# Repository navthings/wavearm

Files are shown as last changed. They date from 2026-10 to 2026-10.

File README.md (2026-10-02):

# wavearm

a little desk robot arm that copies whatever my arm is doing. i wave, it waves back.

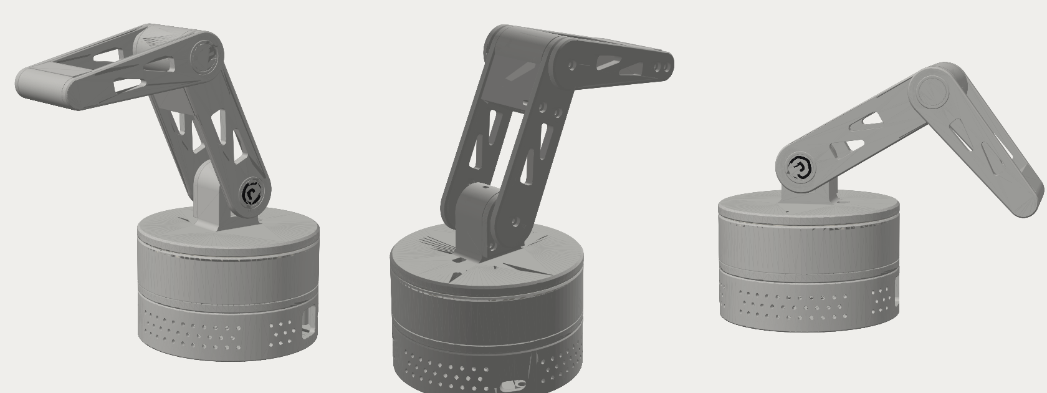
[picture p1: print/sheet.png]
renders


it started as a two joint thing that could only wave. then i found an old raspberry pi 5 in a drawer and it turned into a proper three joint arm: the base spins, and the shoulder and elbow tilt. the pi hides in the base and moves the servos, and my macbook webcam does the watching. it finds my shoulder, elbow and wrist, works out the angles, and sends them to the pi over wifi.

the whole thing is about $40 of parts plus a lot of light grey PLA.

## how it works

```
mac webcam -> mediapipe finds my arm -> shoulder + elbow angles -> wifi -> pi 5 -> three servos
```

the design is all code (`arm3.py`, using cadquery), so every size is a number at the top of the file. change one, run `python3 arm3.py && python3 plates.py` and you get new print files packed onto a1 mini plates. `check3.py` swings both joints through their whole range and makes sure nothing crashes into anything.

it can also do head tracking (`software/track.py`), where the base just turns to look at you. more on the software in [software/README.md](software/README.md).

## what you need

| part | where | price |
|---|---|---|
| 1x MG90S metal gear servo (shoulder, it holds the whole arm up) | [altronics Z6444](https://www.altronics.com.au/product/z6444-mg90s-metal-geared-micro-servo) | $13.95 |
| 2x 9g plastic servo (base and elbow, barely any load) | altronics Z6392 | $9.95 each |
| jumper wires, pin to socket | altronics P1021 | $4.00 |
| M3x10 screws, 25 pack (it uses 12) | altronics H3120A | $2.60 |
| raspberry pi 5 + the official 27W power supply | had one | |
| a usb stick (8gb+) to boot the pi from | had one | |

no soldering, and no tiny M2.5 screws because the pi just sits on printed pegs. the pi boots off a usb stick that plugs into the blue usb port through a window on the right side of the base, so no sd card needed.

## printing

i print on a bambu a1 mini, so everything is laid out on plates in `print/a1mini/`. 0.2mm layers, 3 walls, 15% gyroid, no supports on anything.

everything is packed onto 4 plates, as many parts per plate as fit:

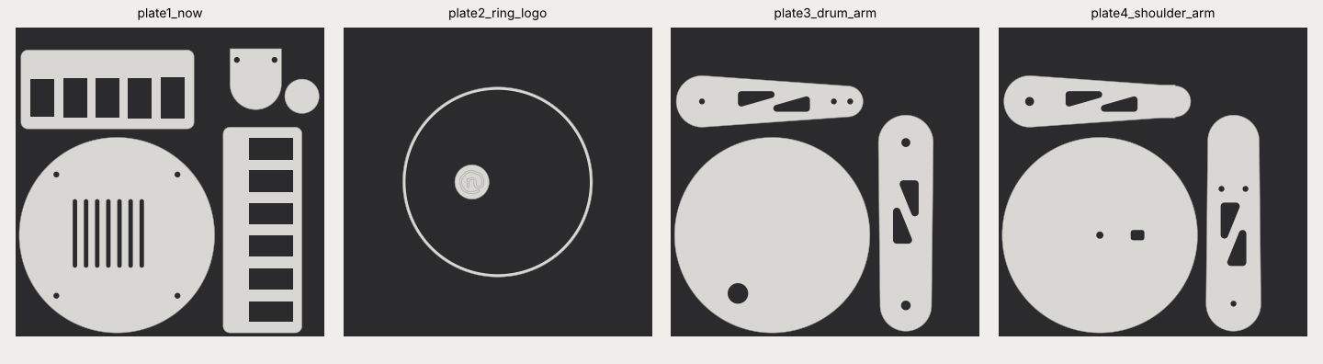
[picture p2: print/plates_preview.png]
plates


| plate | whats on it | when |
|---|---|---|
| plate1_now | tray (25% infill so the base is heavy), both servo gauge strips, servo cover, elbow cap | first. nothing on it depends on servo sizes and theres no pause, so you can leave it running |
| plate2_ring_logo | light ring + logo cap | when youre home, it pauses at 1.6mm to swap colour for the logo |
| plate3_drum_arm | drum, upper arm front, forearm back | after the gauge test |
| plate4_shoulder_arm | shoulder + platter, upper arm back, forearm front | after the gauge test. brim on, the forearm has a tall thin bit |

the gauge strips are rows of slots in slightly different sizes. push each servo into them and the tightest slot it fits is its real size, so you dont need calipers. put those numbers into `arm3.py`, run `python3 arm3.py && python3 plates.py`, then print plates 3 and 4.

the loose STLs and STEP files (for fusion / onshape) are in `print/` too.

## wiring

| servo | signal | 5V | GND |
|---|---|---|---|
| base | pin 32 (GPIO 12) | pin 2 | pin 6 |
| shoulder | pin 33 (GPIO 13) | pin 4 | pin 14 |
| elbow | pin 12 (GPIO 18) | shares pin 2 or 4 | pin 9 |

the pi only has two 5V pins, so the elbow shares one. strip two jumper wires, twist them together, tape it.

## putting it together

1. centre all three servos at 90 degrees before any horns go on, otherwise it waves lopsided
2. pi onto the pegs in the tray, usb-c lined up with the hole at the back and the blue usb ports lined up with the window on the side. plug the boot stick in from outside
3. base servo into the drum, drum onto the tray (4 screws from underneath)
4. ring into the drum, horn into the bottom of the platter, platter onto the servo, screw it down through the little hole in the top of the tower
5. shoulder servo slides into the tower from the back, cover clamps it in
6. elbow servo goes inside the top of the upper arm, then the back plate screws on
7. forearm onto the elbow, back plate on, pivot screws snug but not tight
8. press the caps in

## older stuff

`v1/` has the first version, the two joint waving arm. kept it because the three joint one grew out of it.

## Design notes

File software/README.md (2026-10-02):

# software

your mac webcam watches you, works out where the robot should point, and sends that to the pi over wifi. the pi just moves the servos.

- `armtrack.py` (mac): copies your arm. your shoulder and elbow angles go straight to the robots shoulder and elbow
- `track.py` (mac): head tracking, the base turns to face you
- `arm.py` (pi): receives angles and drives the three servos

## on the mac (arm copy)

```zsh
cd ~/Documents/Projects/wavearm/software
source .venv312/bin/activate
python armtrack.py --pi raspberrypi.local
```

`.venv312` is python 3.12 with mediapipe 0.10.14 (the classic cpu pose model, the newer one crashes on macs trying to use metal). it runs about 15ms a frame.

keys: a = switch which arm it copies, s / e = flip shoulder / elbow direction if it moves the wrong way, left/right = turn the base, w = save, q = quit. stand back far enough that your shoulder, elbow and wrist are all in frame.

## on the pi

add this to `/boot/firmware/config.txt` and reboot (hardware pwm on GPIO 12 and 13, arm.py switches GPIO 18 on itself):

```
dtoverlay=pwm-2chan,pin=12,func=4,pin2=13,func2=4
```

```zsh
scp arm.py pi@raspberrypi.local:~
ssh pi@raspberrypi.local "sudo python3 arm.py"
```

## wiring (no soldering)

| servo | signal | 5V | GND |
|---|---|---|---|
| base (plastic) | pin 32 (GPIO 12) | pin 2 | pin 6 |
| shoulder (metal MG90S) | pin 33 (GPIO 13) | pin 4 | pin 14 |
| elbow (plastic) | pin 12 (GPIO 18) | shares pin 2 or 4 | pin 9 |

the pi only has two 5V pins, so the elbow shares one: strip 1cm off two jumper wires, twist them together, tape it. use the official 27W pi power supply or the pi will reboot when the servos start.

## testing without the pi

`python3 arm.py --dry` in one window, `python armtrack.py --pi 127.0.0.1` in another. arm.py prints the angles instead of moving anything.

## tuning (top of arm.py)

- `PULSE_MIN` / `PULSE_MAX`: if a joint doesnt reach its full swing or buzzes at the ends
- `CENTRE`: if straight up isnt quite straight, change 90 to 85 or 95 for that joint
- `MAX_SPEED`: lower = calmer, higher = snappier

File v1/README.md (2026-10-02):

# wave arm

two joint desk arm. the drum turns to face you, the link swings side to side to wave. a raspberry pi 5 lives in the base, so it runs on its own (camera, face tracking, sprout) with no laptop.

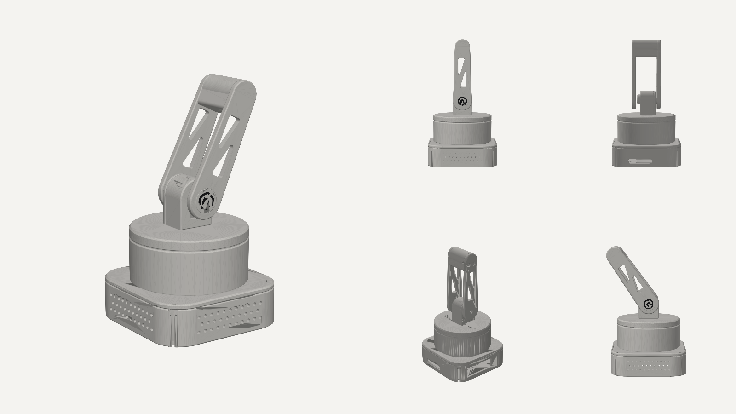
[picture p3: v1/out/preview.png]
preview


## files

- `wavearm.py` the actual design. every size is a variable at the top, change one and rerun `python3 wavearm.py`
- `out/*.step` open these in fusion 360, onshape or autocad (IMPORT) to look around and edit
- `out/wave_arm_assembly.step` everything put together, with dummy servos and the pi in place
- `out/*.stl` already in print orientation, drag straight into bambu studio
- `check.py` checks nothing collides across the whole swing (including the pi in the tray)
- `software/` head tracking: mac webcam finds you, pi moves the arm (see software/README.md)
- `wavearm_esp32.py` the older version with a tiny esp32 board in the drum instead of a pi

## parts list (about A$55 at altronics)

- raspberry pi 5 (already have) + its active cooler + the official 27W usb-c power supply. a weaker charger will make it reboot when the servos move
- 3x MG90S micro servo (2 + 1 spare). altronics Z6444
- male to female jumper wires (servo plug to pi pins)
- M3 button head screws: 4x M3x8 (tray to drum), 2x M3x10 (cover), 1x M3x8 (rear pivot), 2x M3x12 (link)
- 4x M2.5x6 screws for the pi
- 4x 10mm rubber feet
- optional: 470uF capacitor + mini breadboard if the pi reboots when servos start

## printing

- PLA, matte light grey looks closest to the reference. 0.2mm layers, 3 walls, 15% gyroid. tray at 25% so it's heavier
- the tray and the drum are separate prints (tray open side up, drum on its flat lid)
- no supports on anything, every part already sits on its flat face
- hub cap: print `cap.stl` + `cap_logo.stl` together as two colours (AMS), or print `cap_onepiece.stl` and add a filament change at 1.6mm
- print `cap.stl` first and check it presses into the link. if it's loose or tight, change the 0.15 next to `CAP_D` in the code

## build order

1. measure your servos with calipers and fix the `S_` numbers at the top of `wavearm.py` before printing anything big
2. centre both servos at 90 degrees before any horn goes on (one line of code). if you skip this the arm waves lopsided
3. pi into the tray: usb + ethernet at the back opening, 4x M2.5 into the standoffs. servo 1 drops into the cradle in the drum, shaft up, two tab screws. its cable goes out the side slot and down the hole in the drum floor. drum onto the tray, 4x M3x8 up from underneath
4. screw servo 1's horn into the pocket under the platter, push the platter onto the spline, then put the horn screw in from above through the little hole in the top of the tower
5. thread servo 2's cable down the slot in the tower floor, slide the servo in from the back, shaft forward. the cover clamps it, 2x M3x10
6. horn into the pocket on the back of the front link, push onto servo 2's spline, horn screw in. back plate on with 2x M3x12 into the bridge, M3x8 into the rear boss (snug, not tight, it's a pivot)
7. press the hub cap in

## wiring (no soldering)

| servo wire | base servo | shoulder servo |
|---|---|---|
| red (5V) | pin 2 | pin 4 |
| brown (GND) | pin 6 | pin 14 |
| orange (signal) | pin 32 (GPIO 12) | pin 33 (GPIO 13) |

- GPIO 12 and 13 are hardware PWM on the pi 5, so the servos dont jitter. normal software PWM makes them twitch
- the pi gets power through the side slot (usb-c, the plug reaches in about 13mm). hdmi is in the same slot if you ever need a screen

## numbers

- shoulder pivot 103mm up, arm tip 203mm up, footprint 112mm square
- link swings ±90 degrees without hitting anything (`python3 check.py`)

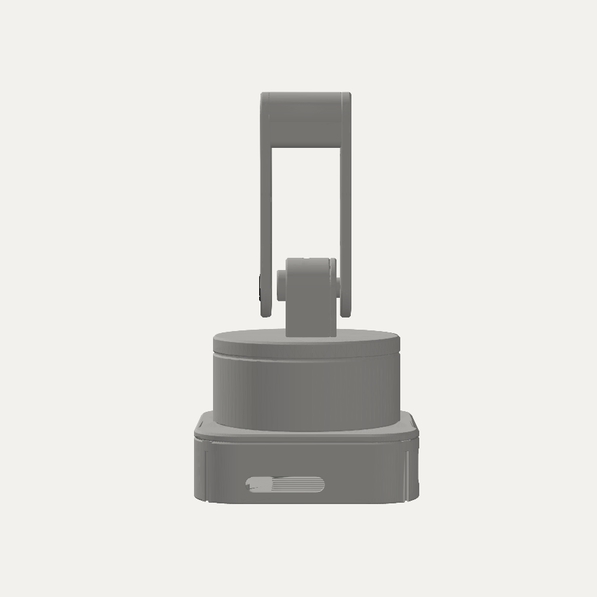
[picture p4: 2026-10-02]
v1/out/render_side.png

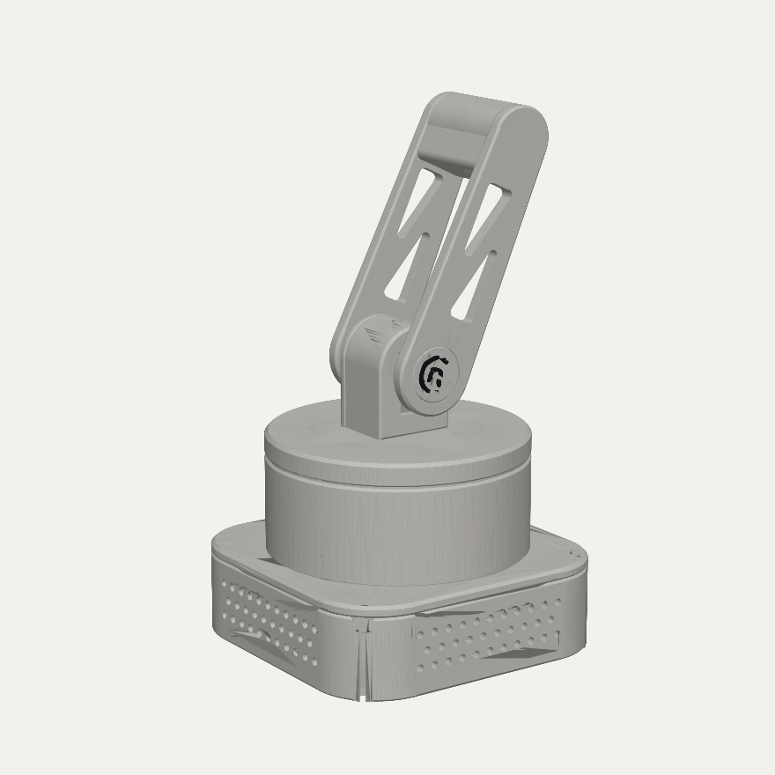
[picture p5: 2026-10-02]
v1/out/render_hero.png

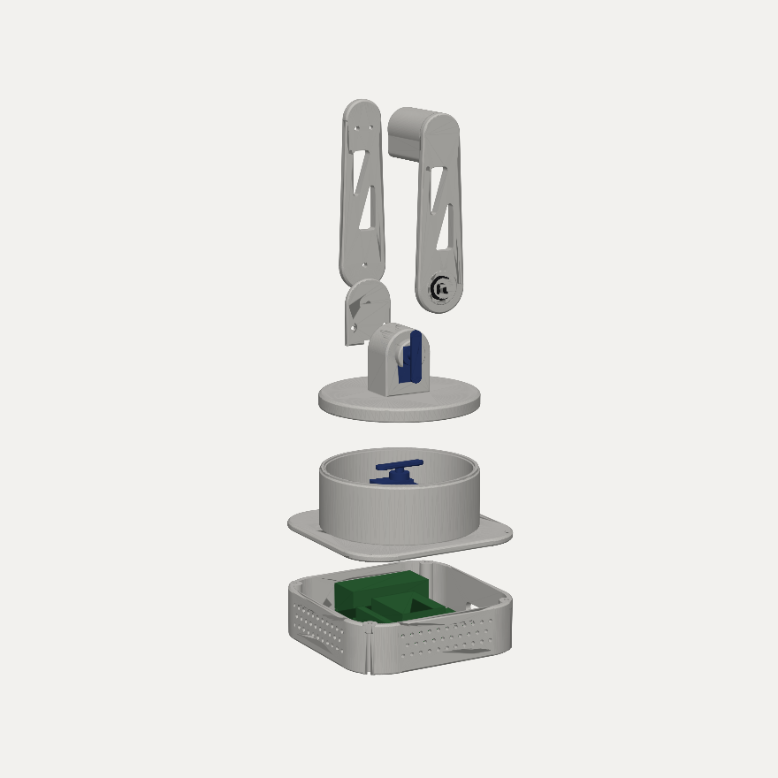
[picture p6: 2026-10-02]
v1/out/render_exploded.png

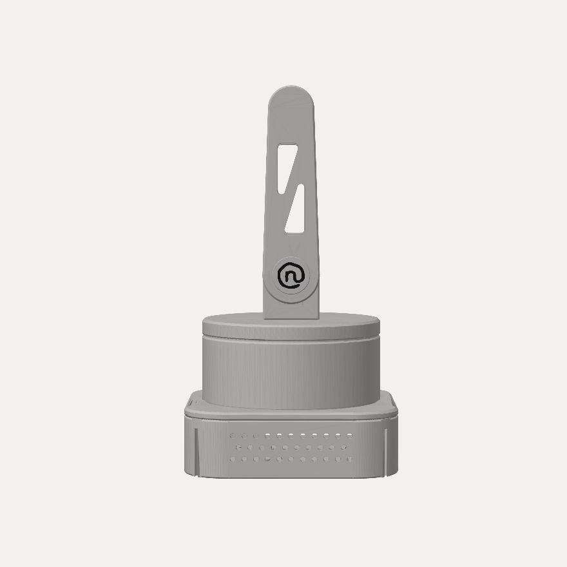
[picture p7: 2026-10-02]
v1/out/render_front.png

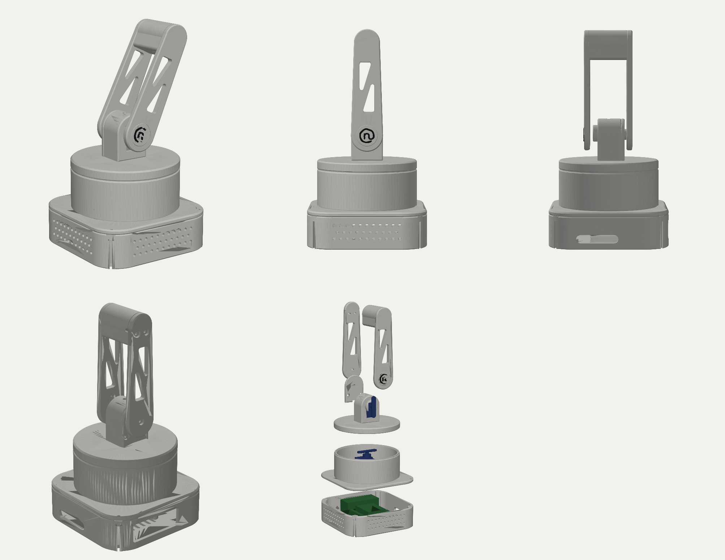
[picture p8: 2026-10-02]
v1/out/render_sheet.png

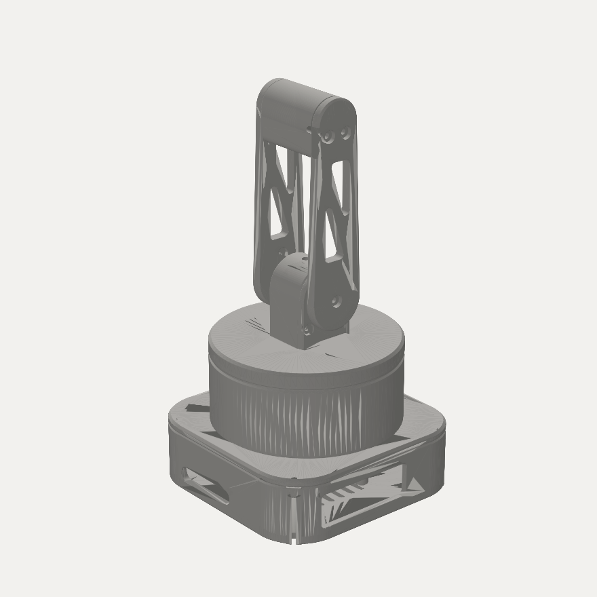
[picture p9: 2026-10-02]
v1/out/render_back.png

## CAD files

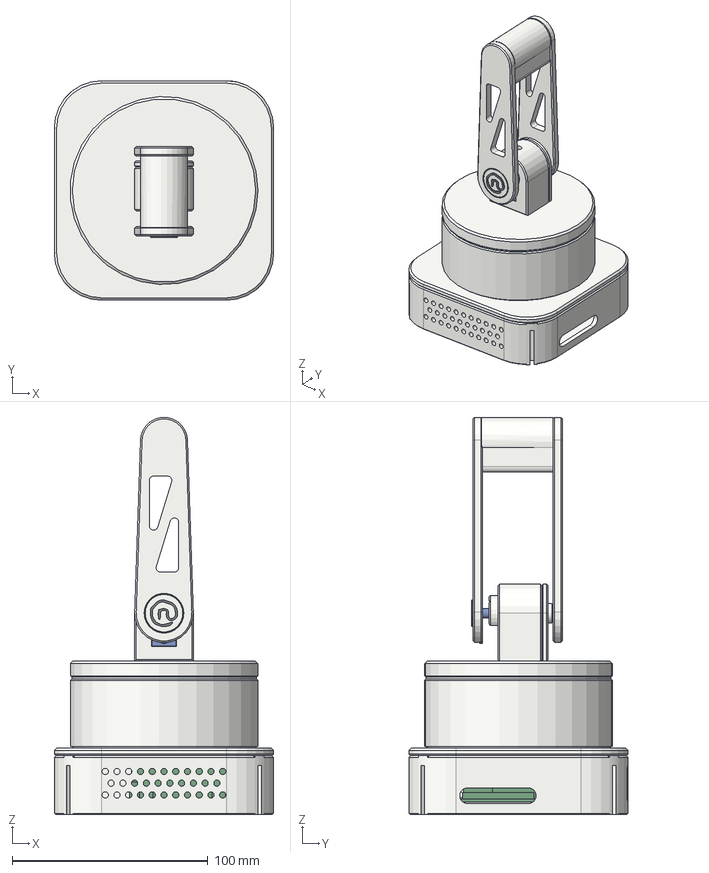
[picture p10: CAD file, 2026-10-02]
v1/out/wave_arm_assembly.step
112.0 x 112.0 x 202.7 mm
tray
base
shoulder
cover
link_front
link_back
cap
cap_logo
servo_base
servo_shoulder
raspberry_pi_5

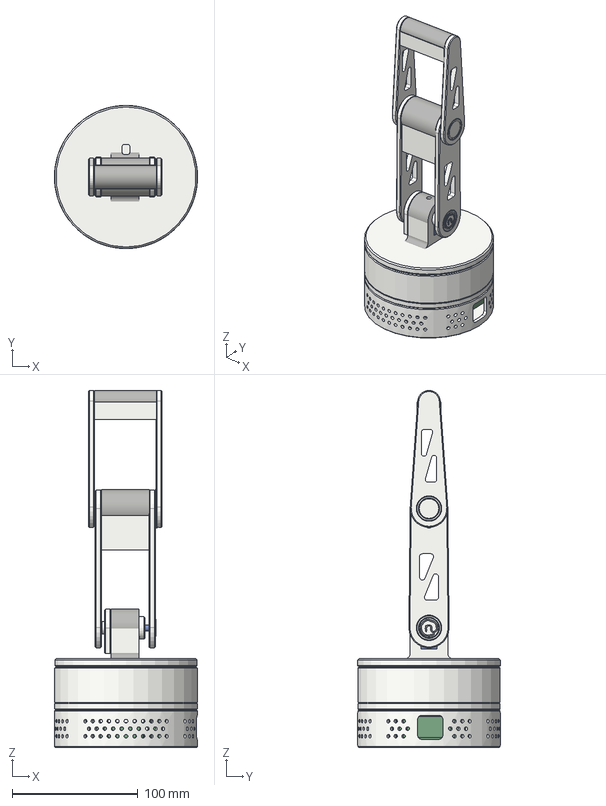
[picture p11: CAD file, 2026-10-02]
print/arm3_assembly.step
114.0 x 114.0 x 284.3 mm
tray
drum
ring
shoulder
cover
up_front
up_back
cap_s
logo_s
fo_front
fo_back
cap_e
servo_base
servo_shoulder
servo_elbow
raspberry_pi_5

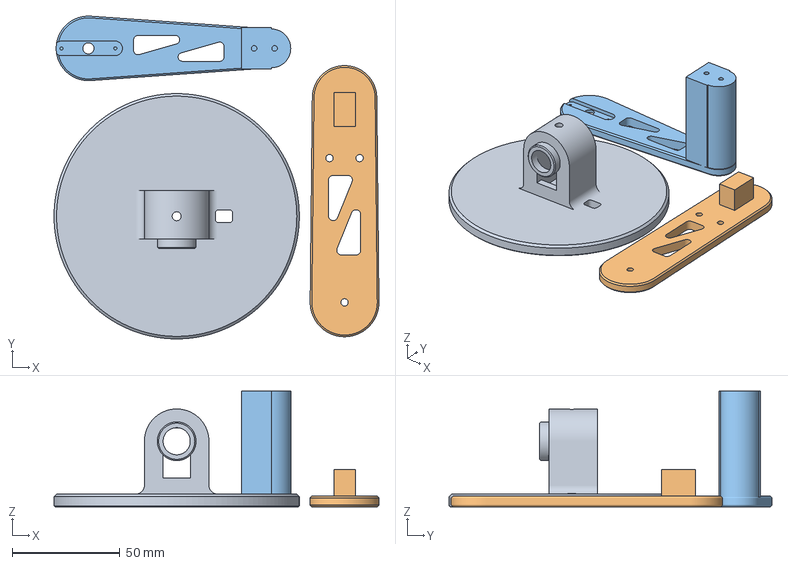
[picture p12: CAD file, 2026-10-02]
print/a1mini/plate4_shoulder_arm.3mf
151.0 x 150.0 x 53.8 mm
shoulder
up_back
fo_front

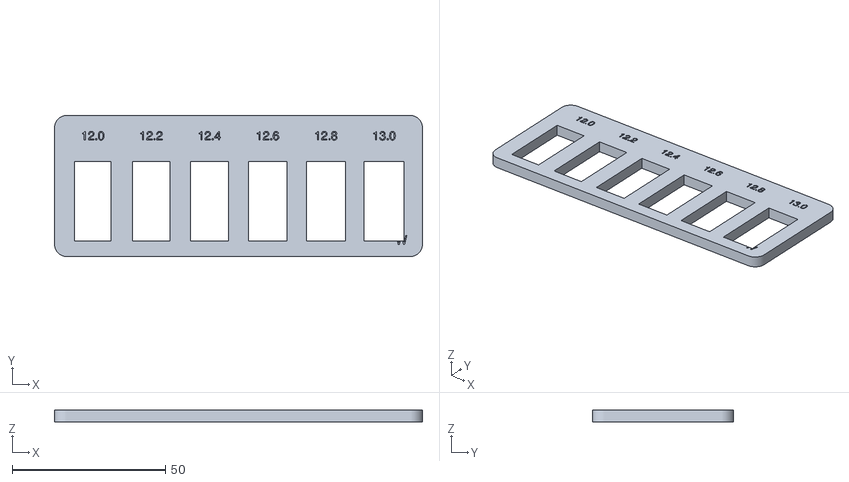
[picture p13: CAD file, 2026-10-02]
print/gauge_width.stl
120.0 x 46.0 x 4.00

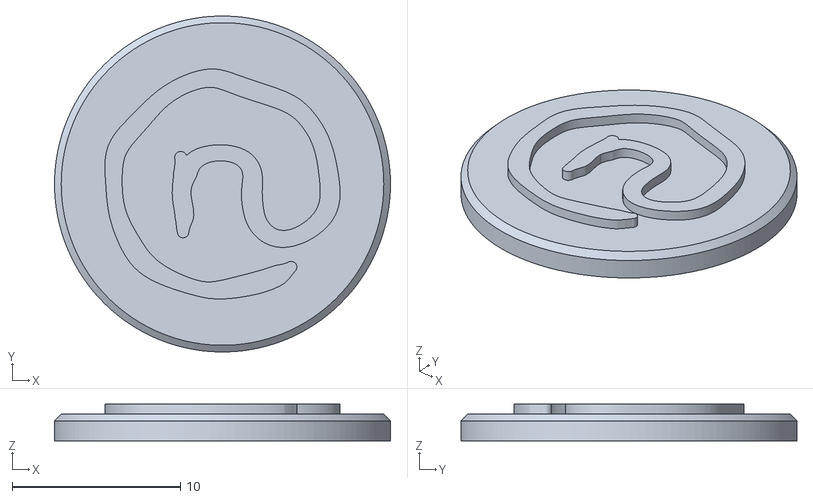
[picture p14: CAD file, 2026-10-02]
v1/out/cap_onepiece.stl
20.0 x 20.0 x 2.20

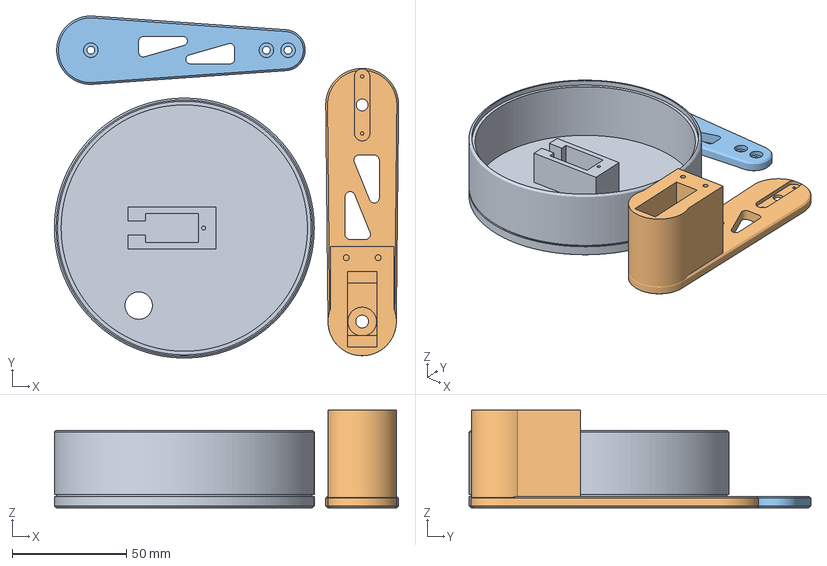
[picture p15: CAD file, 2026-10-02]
print/a1mini/plate3_drum_arm.3mf
151.0 x 150.0 x 42.8 mm
drum
up_front
fo_back

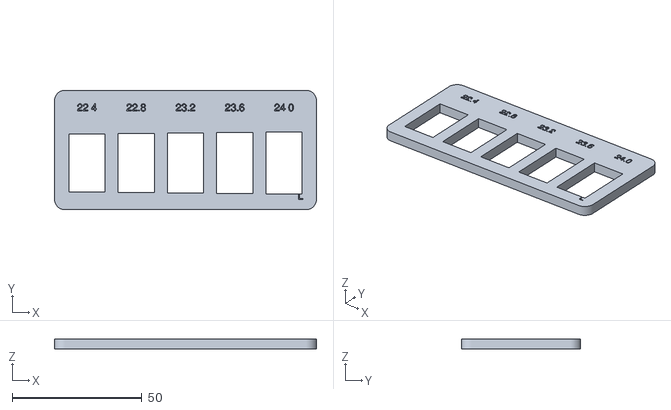
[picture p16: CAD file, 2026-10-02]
print/gauge_length.stl
101.0 x 46.0 x 4.00

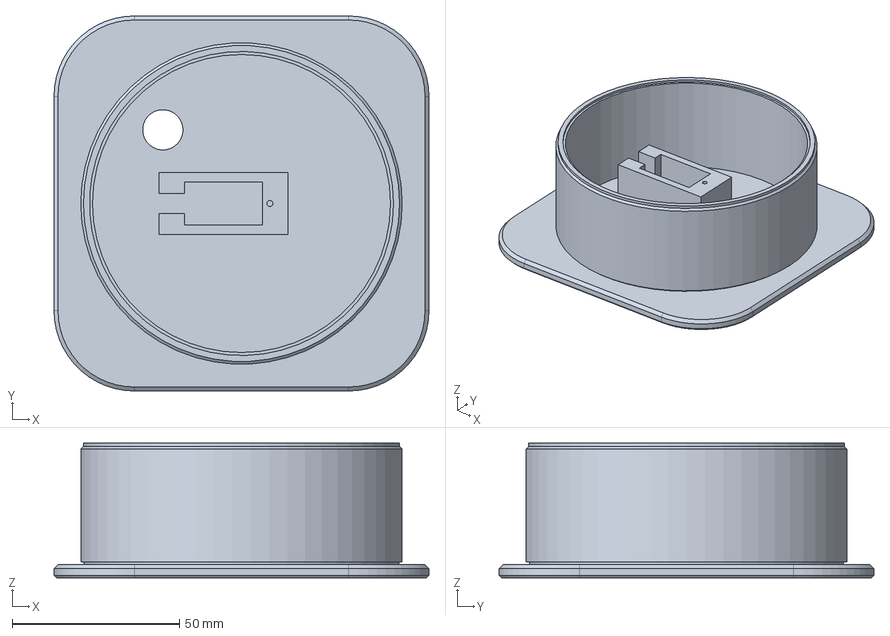
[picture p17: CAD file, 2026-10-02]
v1/out/base.step
112.0 x 112.0 x 40.3 mm

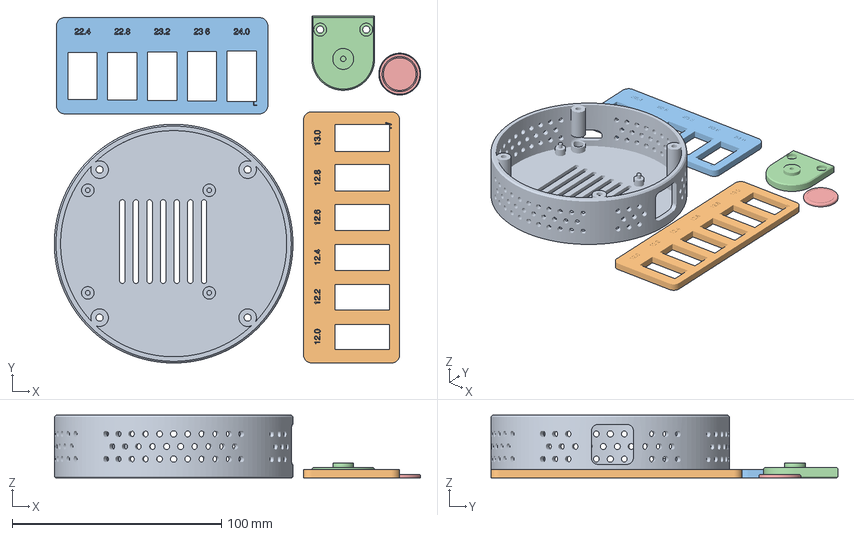
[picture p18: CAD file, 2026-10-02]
print/a1mini/plate1_now.3mf
175.0 x 165.7 x 30.0 mm
tray
gauge_width
gauge_length
cover
cap_elbow

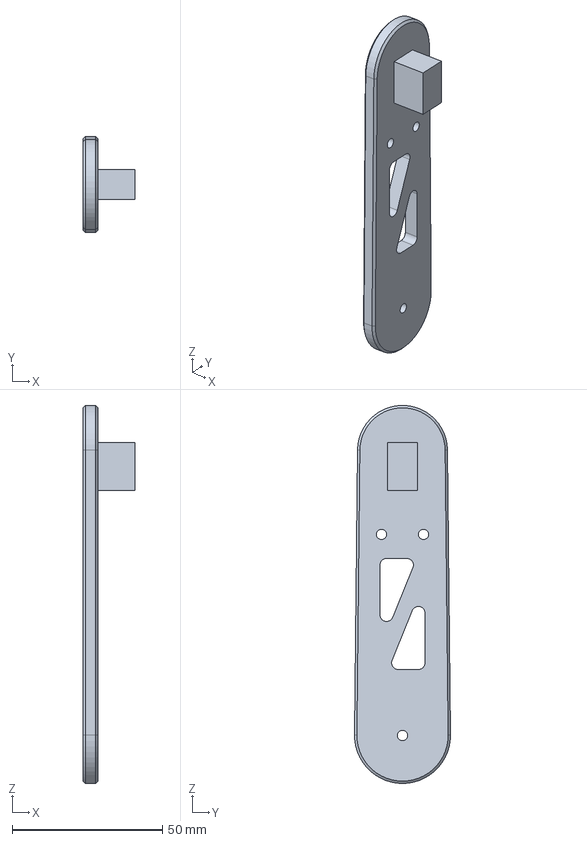
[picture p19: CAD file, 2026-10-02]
print/up_back.step
17.3 x 32.0 x 126.0 mm

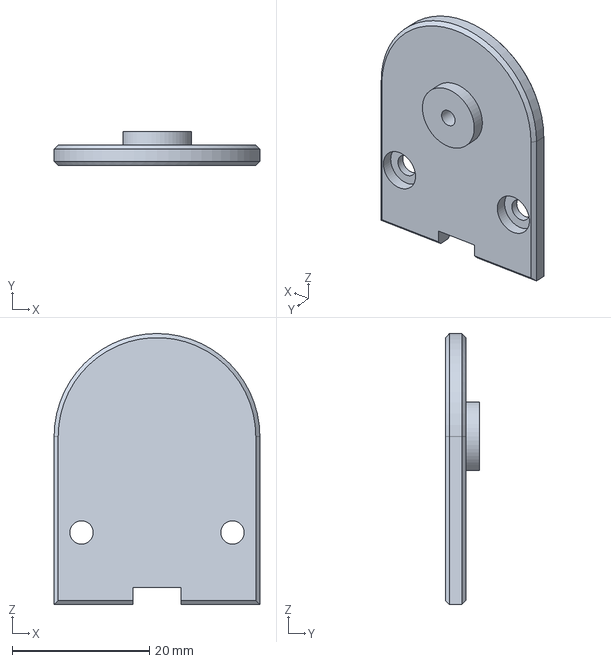
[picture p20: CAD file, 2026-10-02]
v1/out/cover.step
30.0 x 5.00 x 39.5 mm

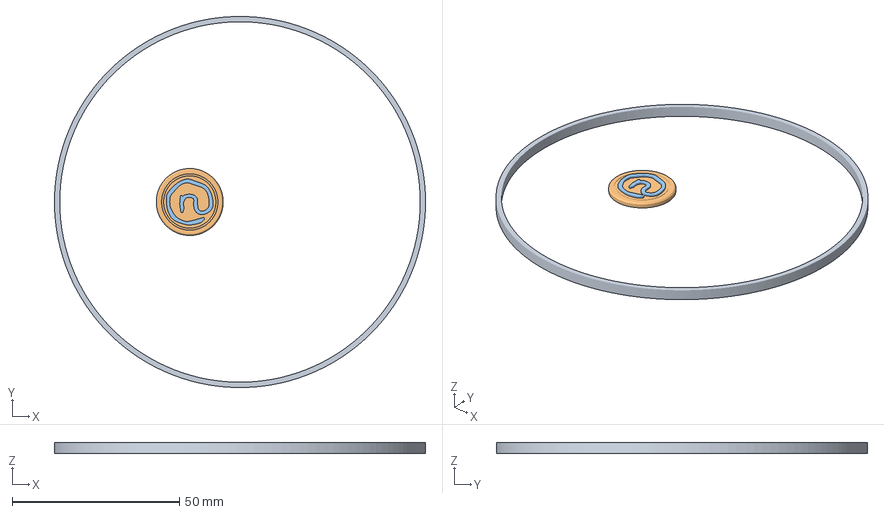
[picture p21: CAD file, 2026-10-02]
print/a1mini/plate2_ring_logo.3mf
110.8 x 110.8 x 3.20 mm
ring
cap_shoulder
cap_shoulder_logo

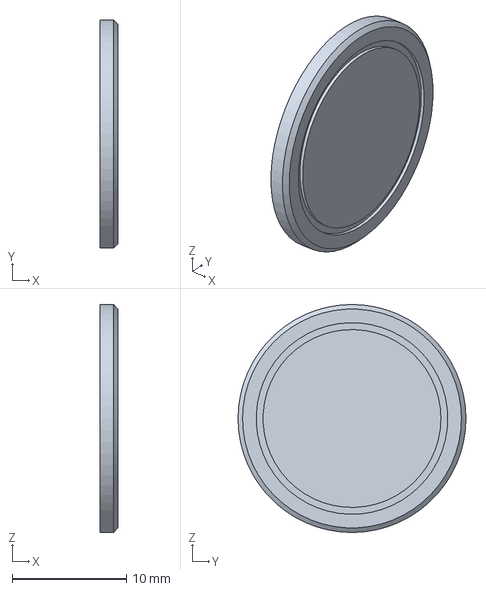
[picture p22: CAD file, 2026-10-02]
print/cap_s.step
1.60 x 20.0 x 20.0 mm

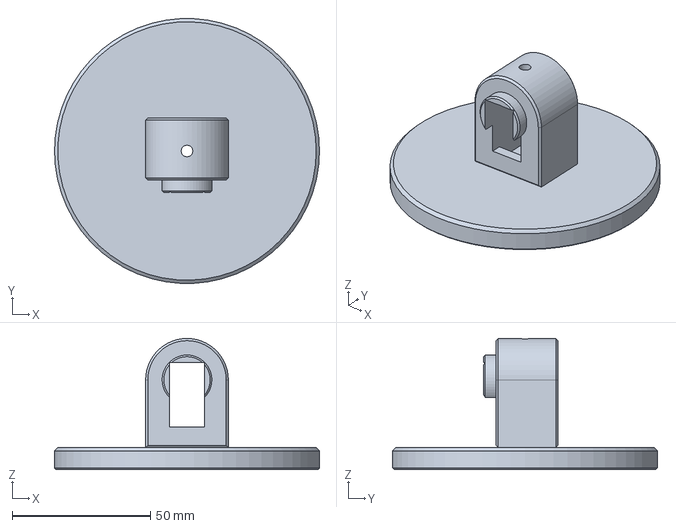
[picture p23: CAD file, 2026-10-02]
v1/out/shoulder.step
96.0 x 95.9 x 47.5 mm

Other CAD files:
print/tray.step
v1/out/cap_logo.step
print/shoulder.step
v1/out/link_front.step
print/cap_e.step
print/cap_elbow.stl
print/cap_shoulder.stl
print/cap_shoulder_logo.stl
print/cover.step
print/cover.stl
print/drum.step
print/drum.stl
print/fo_back.step
print/fo_back.stl
print/fo_front.step
print/fo_front.stl
print/logo_s.step
print/ring.step
print/ring.stl
print/shoulder.stl
print/tray.stl
print/up_back.stl
print/up_front.step
print/up_front.stl
v1/out/base.stl
v1/out/cap.step
v1/out/cap.stl
v1/out/cap_logo.stl
v1/out/cover.stl
v1/out/link_back.step
v1/out/link_back.stl
v1/out/link_front.stl
v1/out/shoulder.stl
v1/out/tray.step
v1/out/tray.stl

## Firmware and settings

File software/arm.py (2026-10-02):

import argparse
import json
import socket
import subprocess
import time
from pathlib import Path

# 500us = 0 degrees, 2500us = 180 degrees. if a joint doesnt reach its full swing or buzzes at the ends, tweak these
PULSE_MIN, PULSE_MAX = 500, 2500
PERIOD_NS = 20_000_000                                    # 50hz servo signal
JOINTS = {"yaw": 0, "shoulder": 1, "elbow": 2}            # pwm channel: GPIO 12, 13, 18
CENTRE = {"yaw": 90.0, "shoulder": 90.0, "elbow": 90.0}   # servo angle when that joint is at 0 (arm straight up, facing forward)
LIMIT = 85.0                                              # stay a little inside the servos' 180 degrees
MAX_SPEED = 200.0                                         # degrees per second
TIMEOUT = 1.5                                             # seconds without messages before it drifts home


class SysfsPWM:
    """Pi 5 hardware pwm. needs dtoverlay=pwm-2chan,pin=12,func=4,pin2=13,func2=4 in /boot/firmware/config.txt"""

    def __init__(self):
        chips = [c for c in Path("/sys/class/pwm").glob("pwmchip*") if (c / "npwm").read_text().strip() == "4"]
        if not chips:
            raise SystemExit("no pwm chip found. add this to /boot/firmware/config.txt and reboot:\n"
                             "dtoverlay=pwm-2chan,pin=12,func=4,pin2=13,func2=4")
        self.chip = chips[0]
        # the overlay only sets up 12 and 13, so switch GPIO 18 to its pwm function (channel 2) by hand
        subprocess.run(["pinctrl", "set", "18", "a3"], check=True)
        for ch in JOINTS.values():
            pwm = self.chip / f"pwm{ch}"
            if not pwm.exists():
                (self.chip / "export").write_text(str(ch))
                time.sleep(0.2)  # udev needs a moment to make the files
            (pwm / "period").write_text(str(PERIOD_NS))
            (pwm / "enable").write_text("1")

    def write(self, joint: str, angle: float):
        us = PULSE_MIN + (PULSE_MAX - PULSE_MIN) * angle / 180
        (self.chip / f"pwm{JOINTS[joint]}" / "duty_cycle").write_text(str(int(us * 1000)))

    def off(self):
        for ch in JOINTS.values():
            (self.chip / f"pwm{ch}" / "enable").write_text("0")


class PrintPWM:
    """--dry: print angles instead of moving anything."""

    def __init__(self):
        self.last, self.now = 0.0, {}

    def write(self, joint: str, angle: float):
        self.now[joint] = angle
        if joint == "elbow" and time.time() - self.last > 0.25:
            self.last = time.time()
            print("   ".join(f"{j} {a:6.1f}" for j, a in self.now.items()))

    def off(self):
        pass


def main():
    ap = argparse.ArgumentParser(description="receive joint angles over wifi and move the servos")
    ap.add_argument("--port", type=int, default=5005)
    ap.add_argument("--dry", action="store_true", help="print instead of driving servos")
    args = ap.parse_args()

    pwm = PrintPWM() if args.dry else SysfsPWM()
    sock = socket.socket(socket.AF_INET, socket.SOCK_DGRAM)
    sock.bind(("0.0.0.0", args.port))
    sock.setblocking(False)

    target = {j: 0.0 for j in JOINTS}
    pos = {j: 0.0 for j in JOINTS}
    last_msg, tick = 0.0, time.monotonic()
    print(f"listening on udp {args.port}")
    try:
        while True:
            while True:
                try:
                    data, _ = sock.recvfrom(1024)
                except BlockingIOError:
                    break
                msg = json.loads(data)
                if "pan" in msg:  # the head tracker calls the base "pan"
                    msg["yaw"] = msg["pan"]
                last_msg = time.monotonic()
                for j in JOINTS:
                    if j in msg:
                        target[j] = max(-LIMIT, min(LIMIT, float(msg[j])))
            if time.monotonic() - last_msg > TIMEOUT:
                target = {j: 0.0 for j in JOINTS}

            now = time.monotonic()
            step, tick = MAX_SPEED * (now - tick), now
            for j in JOINTS:
                pos[j] += max(-step, min(step, target[j] - pos[j]))
                pwm.write(j, CENTRE[j] + pos[j])
            time.sleep(0.01)
    except KeyboardInterrupt:
        pass
    finally:
        pwm.off()


if __name__ == "__main__":
    main()

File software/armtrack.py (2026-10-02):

import argparse
import json
import math
import socket
import time
from pathlib import Path

import cv2
import mediapipe as mp

HERE = Path(__file__).parent
CALIB = HERE / "arm_calibration.json"

# landmark ids: (shoulder, elbow, wrist) for your right and left arm
ARMS = {"right": (12, 14, 16), "left": (11, 13, 15)}
DEFAULTS = {"arm": "right", "yaw": 85.0, "shoulder_sign": 1, "elbow_sign": 1}
LIMIT = 90.0            # every servo does 180 degrees, so +-90 from centre
SMOOTH = 0.3
MIN_VIS = 0.5           # ignore the arm if mediapipe isnt sure it can see it


def load_calib() -> dict:
    return {**DEFAULTS, **json.loads(CALIB.read_text())} if CALIB.exists() else dict(DEFAULTS)


def arm_angles(lm, arm: str, cal: dict):
    """Your shoulder/elbow/wrist in the image -> robot (shoulder, elbow) degrees, or None if not visible."""
    s, e, w = (lm[i] for i in ARMS[arm])
    if min(s.visibility, e.visibility, w.visibility) < MIN_VIS:
        return None
    ux, uy = e.x - s.x, e.y - s.y            # upper arm, image y points down
    fx, fy = w.x - e.x, w.y - e.y            # forearm
    shoulder = math.degrees(math.atan2(ux, -uy))                       # 0 = arm straight up
    elbow = math.degrees(math.atan2(ux * fy - uy * fx, ux * fx + uy * fy))  # 0 = arm straight
    clamp = lambda v: max(-LIMIT, min(LIMIT, v))
    return clamp(shoulder * cal["shoulder_sign"]), clamp(elbow * cal["elbow_sign"])


def main():
    ap = argparse.ArgumentParser(description="copy your arm with the robot arm")
    ap.add_argument("--pi", default="raspberrypi.local")
    ap.add_argument("--port", type=int, default=5005)
    ap.add_argument("--camera", type=int, default=0)
    args = ap.parse_args()

    # the classic cpu pose model (mediapipe 0.10.14). the newer tasks api crashes on some macs trying to use metal
    pose = mp.solutions.pose.Pose(model_complexity=0, min_detection_confidence=0.5, min_tracking_confidence=0.5)

    cap = cv2.VideoCapture(args.camera)
    waited = 0
    while not cap.isOpened() and waited < 30:
        # opencv asks macos for permission then gives up straight away, so keep retrying while the popup is up
        if waited == 0:
            print("waiting for camera permission, click allow on the popup...")
        time.sleep(1)
        waited += 1
        cap = cv2.VideoCapture(args.camera)
    if not cap.isOpened():
        raise SystemExit("no camera. run this from apple terminal, or check system settings > privacy > camera")

    addr = (socket.gethostbyname(args.pi), args.port)
    sock = socket.socket(socket.AF_INET, socket.SOCK_DGRAM)
    cal = load_calib()
    shoulder = elbow = 0.0
    print(f"sending to {addr[0]}:{addr[1]}. keys: a = switch arm, s/e = flip shoulder/elbow, left/right = turn base, w = save, q = quit")

    while True:
        ok, frame = cap.read()
        if not ok:
            raise SystemExit("lost the webcam")
        rgb = cv2.cvtColor(frame, cv2.COLOR_BGR2RGB)
        res = pose.process(rgb)
        msg = {"t": time.time(), "yaw": cal["yaw"]}
        h, w = frame.shape[:2]
        if res.pose_landmarks:
            lm = res.pose_landmarks.landmark
            angles = arm_angles(lm, cal["arm"], cal)
            if angles:
                shoulder += SMOOTH * (angles[0] - shoulder)
                elbow += SMOOTH * (angles[1] - elbow)
                msg.update(shoulder=round(shoulder, 1), elbow=round(elbow, 1))
            pts = [(int(lm[i].x * w), int(lm[i].y * h)) for i in ARMS[cal["arm"]]]
            cv2.line(frame, pts[0], pts[1], (80, 200, 120), 6)
            cv2.line(frame, pts[1], pts[2], (80, 160, 240), 6)
            for p in pts:
                cv2.circle(frame, p, 9, (255, 255, 255), -1)
        sock.sendto(json.dumps(msg).encode(), addr)

        view = cv2.flip(frame, 1)  # mirror the preview so it feels natural
        text = f"{cal['arm']} arm   shoulder {shoulder:+.0f}   elbow {elbow:+.0f}   base {cal['yaw']:+.0f}"
        cv2.putText(view, text, (14, 32), cv2.FONT_HERSHEY_SIMPLEX, 0.8, (255, 255, 255), 2)
        cv2.imshow("arm copy", view)
        key = cv2.waitKeyEx(1)
        if key in (ord("q"), 27):
            break
        elif key == ord("a"):
            cal["arm"] = "left" if cal["arm"] == "right" else "right"
        elif key == ord("s"):
            cal["shoulder_sign"] *= -1
        elif key == ord("e"):
            cal["elbow_sign"] *= -1
        elif key in (2, 63234, 65361):
            cal["yaw"] = max(-LIMIT, cal["yaw"] - 5)
        elif key in (3, 63235, 65363):
            cal["yaw"] = min(LIMIT, cal["yaw"] + 5)
        elif key == ord("w"):
            CALIB.write_text(json.dumps(cal, indent=2))
            print("saved", CALIB)

    cap.release()
    cv2.destroyAllWindows()


if __name__ == "__main__":
    main()

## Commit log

2026-10-02 desk arm: 3 joint design, a1 mini plates, arm copying + head tracking
    [arm3_assembly.step, base.step, base.stl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]
2026-10-02 side window for the usb boot stick, plates script
    [arm3_assembly.step, cap_e.step, cap_s.step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]
2026-10-02 pack the plates tighter, 4 plates instead of 7
    [gauge_length.stl, gauge_width.stl, plate0_servo_gauge.3mf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]
